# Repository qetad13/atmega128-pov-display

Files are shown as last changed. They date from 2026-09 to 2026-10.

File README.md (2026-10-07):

# ATmega128 POV Display — 회전 LED 잔상 디스플레이

> 마이크로프로세서 수업 Term Project · **2025.08 – 2025.11** · 4인 팀 (팀장) — 회로·PCB·펌웨어·기구 설계 전담

## 프로젝트 개요

| | |
|---|---|
| **소개** | 세로 한 줄로 배치한 **RGB LED 16개**를 모터로 회전시키고, 회전에 맞춰 열(column) 데이터를 빠르게 바꿔 **잔상(POV)으로 글자와 그림을 공중에 그리는** 디스플레이. LED 구동 PCB 설계 → 펌웨어 → 3D 프린팅 기구까지 직접 구현했습니다. |
| **기획 의도** | LED 16개는 그 자체로는 세로 **선** 하나에 불과합니다. 하지만 이 선을 회전시키면서 정확한 타이밍에 빛을 바꾸면, 사람 눈의 잔상 효과로 선이 지나간 자리가 **면**이 되어 글자와 그림이 떠오릅니다. **부품 수를 늘리는 대신 시간으로 해상도를 만든다**는 발상에 끌려 주제로 골랐습니다.<br><br>같은 발상을 배선에도 적용했습니다. RGB LED 16개를 직접 제어하려면 핀이 48개 필요하지만, 시프트 레지스터 6개를 한 줄로 엮어 데이터를 직렬로 흘려보내면 **핀 3개면 충분합니다.** 수업에서 배운 ATmega128의 **타이머 · PWM · 외부 인터럽트 · GPIO 제어**를 이 하나의 작품에 통합했고, 이전 프로젝트에서 겪은 만능기판 배선의 한계를 넘기 위해 **KiCad로 PCB를 직접 설계**했습니다. |
| **하이라이트** | 🔆 **선 → 면** : LED 한 줄(16개)을 회전시켜 잔상으로 2차원 화면 구현<br>📌 **48 → 3** : 74HC595 체인으로 LED 48채널을 MCU 핀 3개로 제어<br>🎨 **단색 8행 → RGB 16행** : 해상도 2배, 6색 · 6단계 밝기 표현 |
| **내 역할** | **팀장** — 회로 설계, PCB 아트웍·제작, 펌웨어(LED 보드 · 모터 보드), 기구 3D 모델링, 설계 문서 |
| **기여도** | **90%** — 하드웨어·펌웨어·기구 설계를 사실상 단독으로 구현 (자세한 내용은 [내 담당 범위](#내-담당-범위)) |

## 주요 사양

| 항목 | 내용 |
|---|---|
| MCU | ATmega128 × 2 (LED 보드 / 모터 보드) |
| LED | RGB LED 16개 (16행 × R·G·B = 48채널) |
| LED 드라이버 | 74HC595 ×6 데이지 체인 (48비트) — **MCU 핀 3개로 48채널 구동** |
| 모터 | DC 모터 + L298N 모터 드라이버, Timer0 Fast PWM 속도 제어 |
| 입력 | 택트 스위치 → 외부 인터럽트 (LED 4개 + 모터 3개) |
| 기능 | 6색 전환 · 6단계 밝기 · 패턴 2종(글자 `ISA` / 하트) · 모터 속도 ±, 일시정지 |
| 개발 환경 | CodeVisionAVR (C), KiCad 9, Fusion 360 |
| 상태 | **완료** — 2025.08 – 2025.11 마이크로프로세서 수업 텀프로젝트 (이후 추가 개발 없음) |

<p align="center">
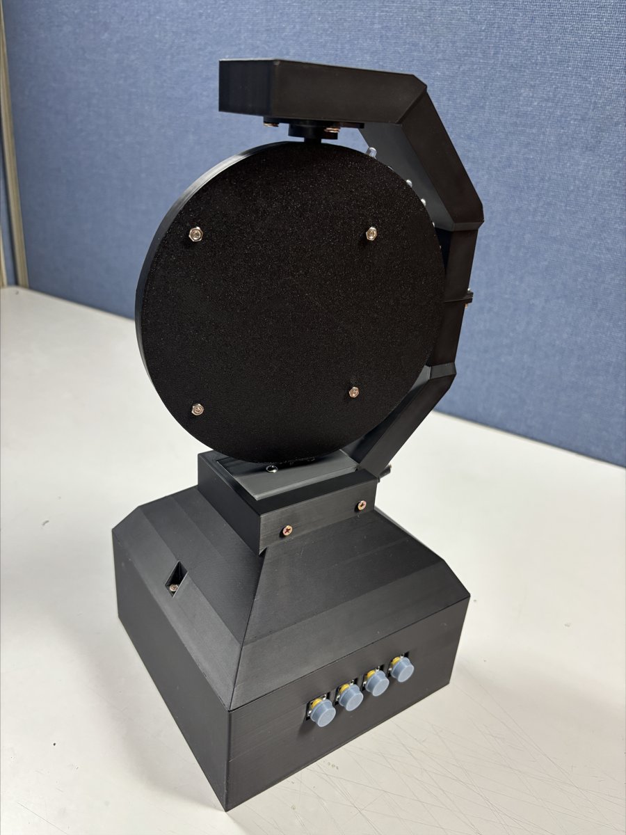
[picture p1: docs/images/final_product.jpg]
  
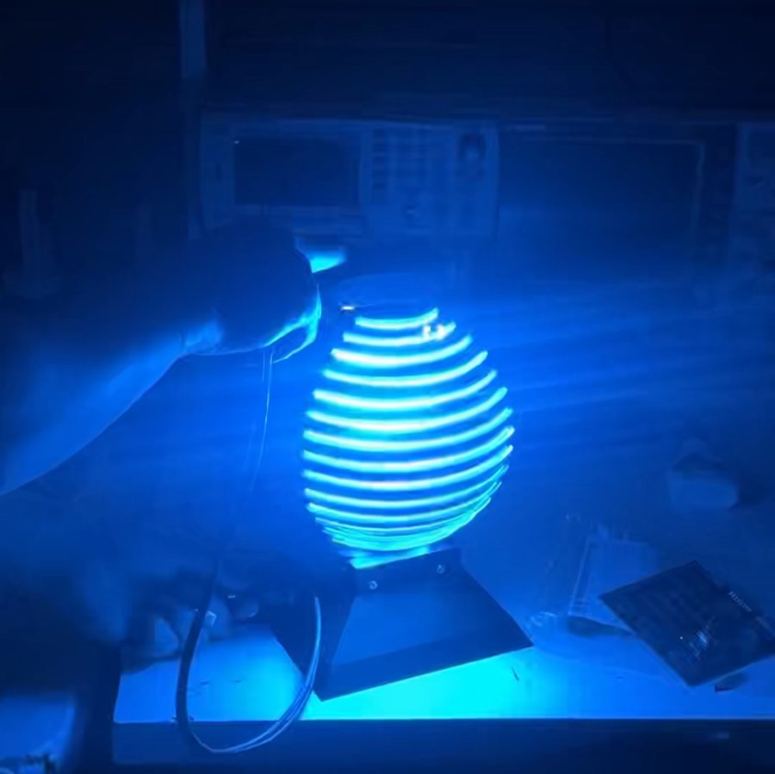
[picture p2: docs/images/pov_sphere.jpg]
  
  <br><sub>왼쪽 완성품 · 오른쪽 회전 중 잔상 — LED 한 줄이 회전하며 구(球) 형태의 면을 만듦</sub>
</p>

---

## 시스템 구조



- **고정부**: 12V 어댑터 → L298N이 모터를 구동하고, L298N의 5V 출력으로 모터 보드와 회전부에 전원 공급
- **회전부**: 전원은 **슬립링**을 통해 회전판 위 LED 보드로 전달되며, MCU가 74HC595 체인으로 RGB LED 16개를 구동

### 동작 원리

1. **LED 한 열 출력** — 16비트 열 패턴을 색상에 따라 R/G/B 채널에 배치하고, B → G → R 순서로 48비트를 시프트한 뒤 RCLK로 한 번에 래치
   - 비트가 `0`이면 LED 켜짐(Active-Low), `0xFFFF`는 전체 소등
2. **밝기 (소프트웨어 PWM)** — 한 열을 `uptime` ms 동안 켜고 `7 - uptime` ms 동안 꺼서, 7 ms 주기 안에서 듀티비를 1/7 ~ 6/7로 조절
3. **패턴** — 회전하는 동안 열 데이터를 순서대로 바꿔 출력하면 잔상으로 2차원 이미지가 보임
   - `ISA` 글자: 24열 (글자당 8열), 하트: 12열
4. **모터 속도** — Timer0 Fast PWM의 `OCR0` 값(0~254)을 인터럽트로 ±10씩 바꿔 L298N ENA에 입력

### 제어 흐름



### 핀 배치

**LED 보드 (ATmega128 #1)**

| 핀 | 방향 | 용도 |
|---|---|---|
| PA0 | 출력 | 74HC595 SER / DS (직렬 데이터) |
| PA1 | 출력 | 74HC595 SRCLK / SHCP (시프트 클럭) |
| PA2 | 출력 | 74HC595 RCLK / STCP (래치 클럭) |
| PD0 (INT0) | 입력, 풀업 | 색상 전환 (빨 → 초 → 파 → 노 → 마젠타 → 청록) |
| PD1 (INT1) | 입력, 풀업 | 밝기 변경 (1 ↔ 6 단계 왕복) |
| PD2 (INT2) | 입력, 풀업 | 패턴 1: `ISA` 글자 |
| PD3 (INT3) | 입력, 풀업 | 패턴 2: 하트 |

**모터 보드 (ATmega128 #2)**

| 핀 | 방향 | 용도 |
|---|---|---|
| PB4 (OC0) | 출력 | PWM → L298N ENA |
| PA0 / PA1 | 출력 | L298N IN1 / IN2 (회전 방향 고정) |
| PD0 (INT0) | 입력, 풀업 | 속도 +10 (최대 254) |
| PD1 (INT1) | 입력, 풀업 | 속도 −10 (최소 1) |
| PD2 (INT2) | 입력, 풀업 | 일시정지 / 재시작 (직전 속도 복원, 첫 시작 160) |

인터럽트는 모두 하강 에지 트리거(`EICRA`)입니다.

---

## 폴더 구조

```
atmega128-pov-display/
├─ firmware/                  CodeVisionAVR C 소스
│  ├─ led_board/main.c        74HC595 48비트 시프트 출력, 색상·밝기·패턴 제어
│  └─ motor_board/main.c      Timer0 Fast PWM 모터 속도 제어
├─ hardware/
│  └─ pcb/                    KiCad 9 프로젝트 (LED 보드)
│     ├─ MPMP.kicad_pro / .kicad_sch / .kicad_pcb
│     └─ gerber/              제작용 Gerber + 드릴 파일
├─ mechanical/                3D 프린팅 부품 (STL)
│  ├─ rotor_plate.stl         회전판 (PCB 장착)
│  ├─ rotor_cover_v2.stl      회전판 덮개
│  ├─ support_upper.stl       지지대 (위)
│  ├─ support_lower.stl       지지대 (아래)
│  ├─ base.stl                받침대
│  └─ base_support.stl        받침대 하부 받침
└─ docs/
   ├─ images/                 블록 다이어그램, 플로우차트, PCB · 3D · 결과 사진
   └─ videos/                 동작 영상
```

---

## 하드웨어

### LED 보드 PCB

- **크기**: 90.3 × 87.2 mm, 2층, 두께 1.6 mm (KiCad 9)
- **구성**
  - ATmega128-16A (TQFP-64) + 크리스털, 22 pF 부하 커패시터, 리셋 스위치
  - 74HC595 × 6 (R·G·B 각 2개, 채널당 16비트) + 칩별 0.1 µF 바이패스 커패시터
  - 8연 저항 네트워크(R_Network08) × 2
  - LED 연결 패드 48개 (R/G/B × 16), 10핀 ISP 헤더 (PE0 / PE1 / PB1 / RESET)
  - 고정용 마운팅 홀 4개
- 48채널 LED 배선을 회전체에 싣기 위해 MCU와 시프트 레지스터를 한 장의 보드로 통합

| PCB 레이아웃 | PCB 3D 뷰 | 회전판 조립 (LED 48채널 배선) |
|:---:|:---:|:---:|
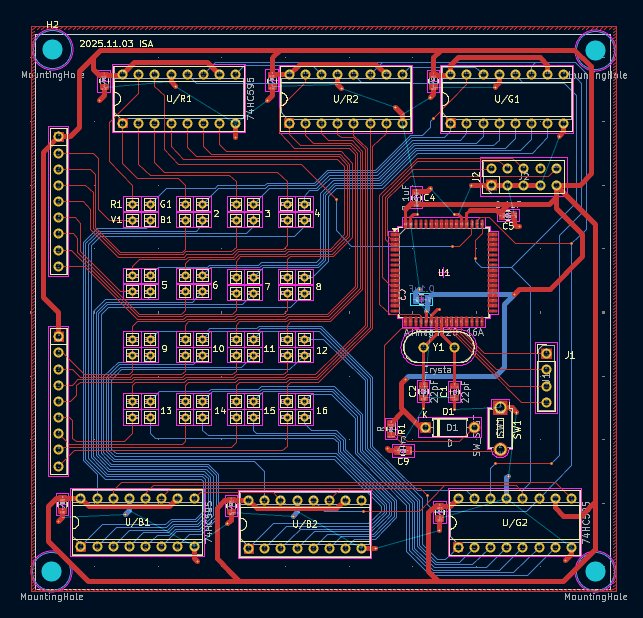
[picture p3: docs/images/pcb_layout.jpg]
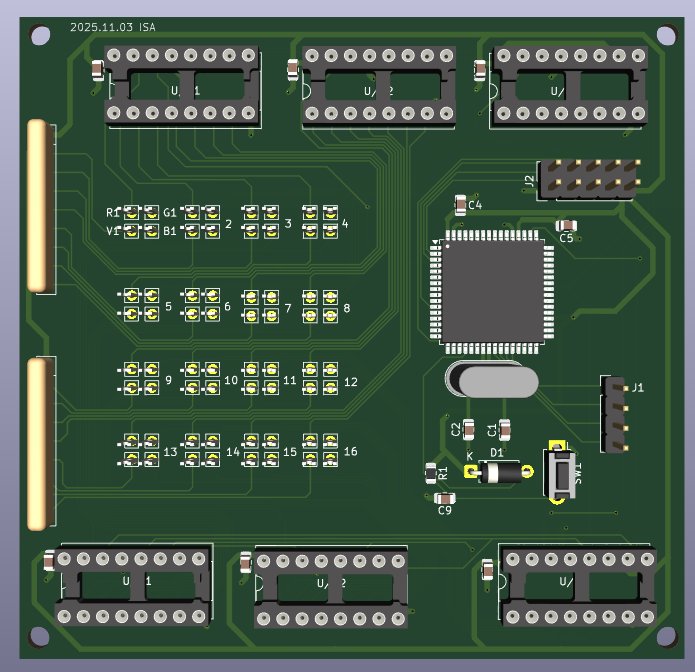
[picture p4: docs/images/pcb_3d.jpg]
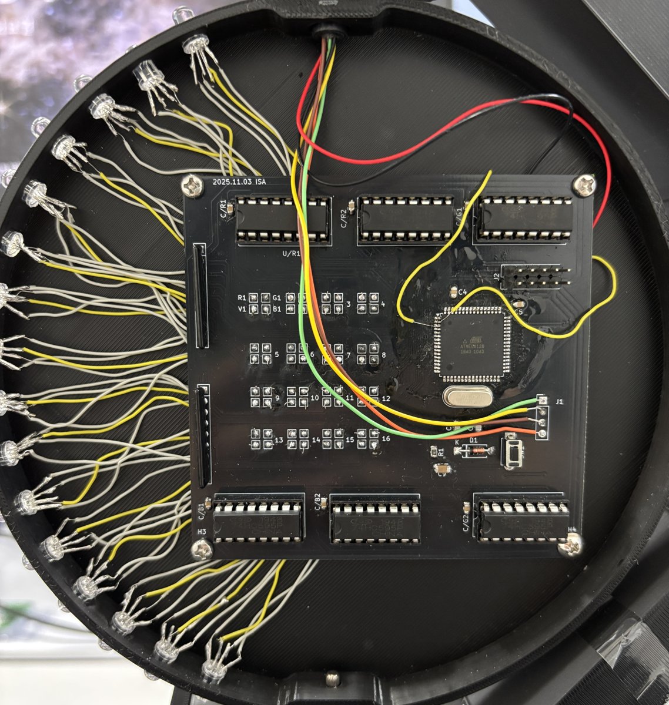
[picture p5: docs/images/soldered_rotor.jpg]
|  |  |  |

브레드보드 테스트를 거친 뒤 PCB로 제작했습니다 ([브레드보드 사진](docs/images/breadboard.jpg)).

### 기구부

- 회전판에 PCB와 LED를 고정하고, 모터 축에 연결해 회전
- 지지대(위/아래)와 받침대로 모터와 회전부를 고정
- 회전부 전원은 슬립링을 통해 공급 (회전하는 LED 보드에 VCC · GND 전달)

| 회전판 · 덮개 | 지지대 · 받침대 | 최종 조립 모델 |
|:---:|:---:|:---:|
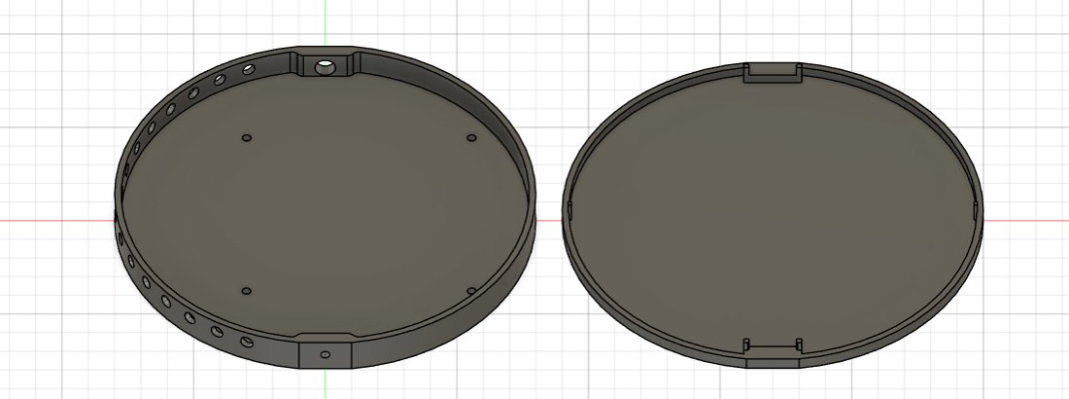
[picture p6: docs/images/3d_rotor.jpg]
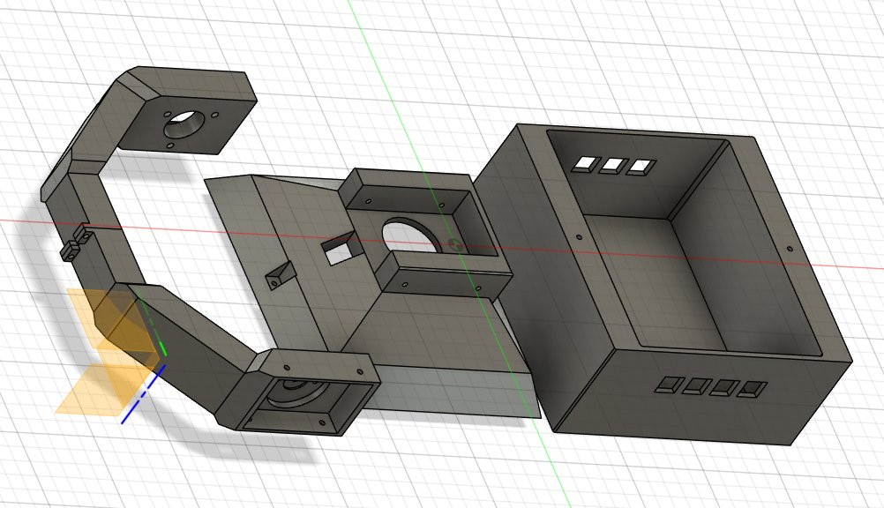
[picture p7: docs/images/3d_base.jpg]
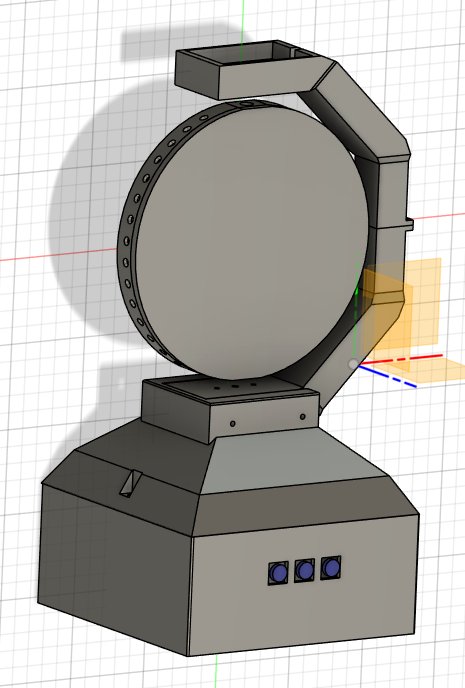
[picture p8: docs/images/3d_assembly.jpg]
|  |  |  |

---

## 결과

### RGB 출력

| Red | Green | Blue |
|:---:|:---:|:---:|
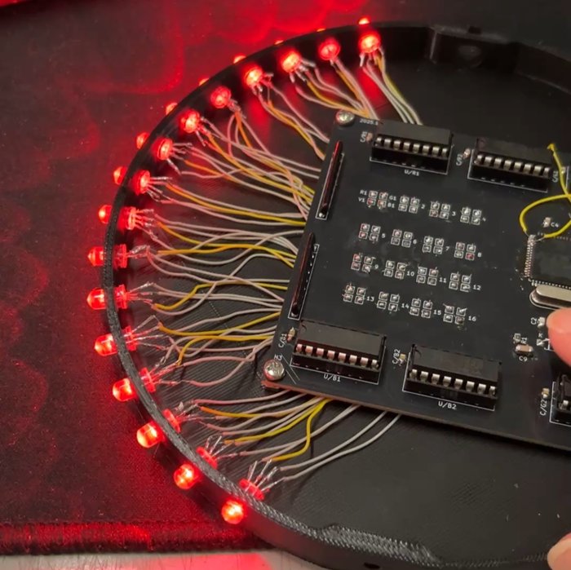
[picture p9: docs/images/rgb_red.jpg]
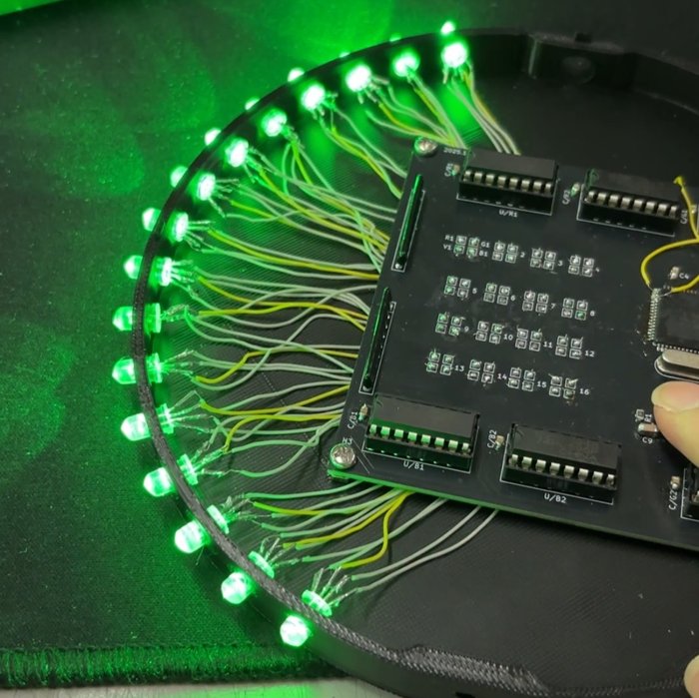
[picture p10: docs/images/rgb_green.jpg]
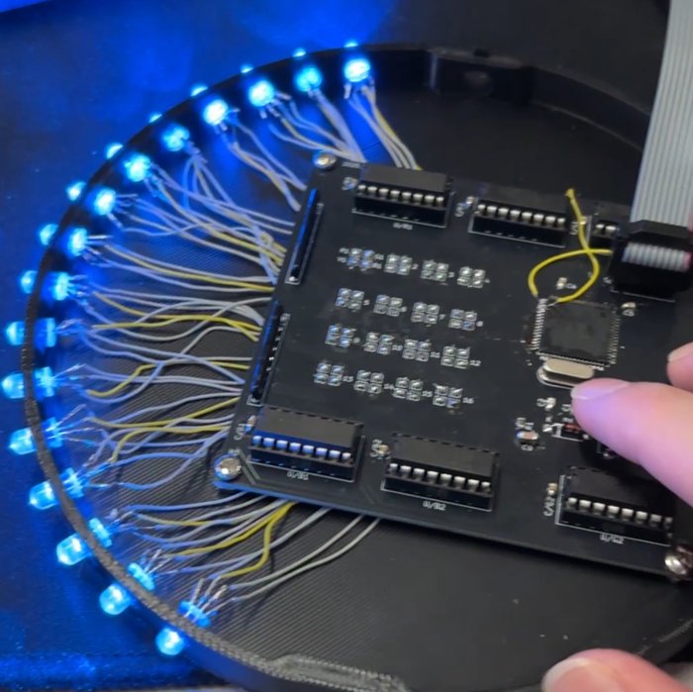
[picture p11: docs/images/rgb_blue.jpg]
|  |  |  |

### 잔상으로 글자 출력 (`ISA`)

| I | S | A |
|:---:|:---:|:---:|
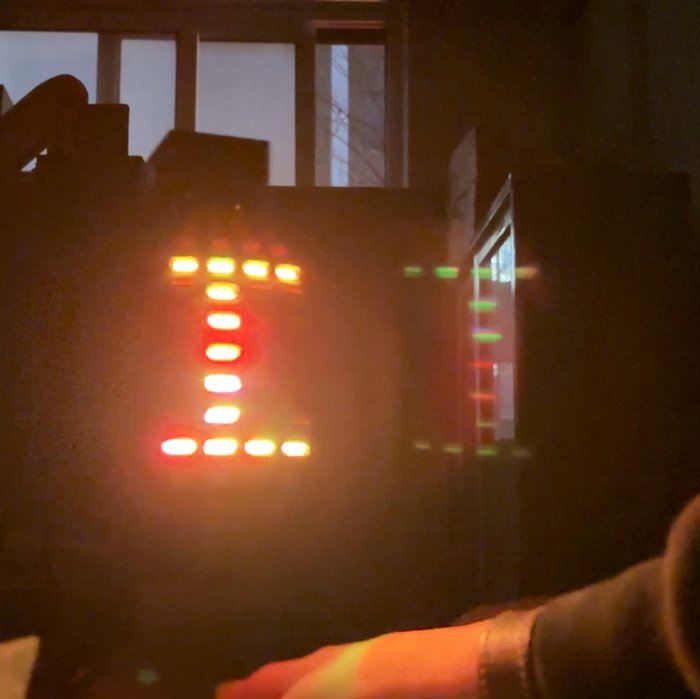
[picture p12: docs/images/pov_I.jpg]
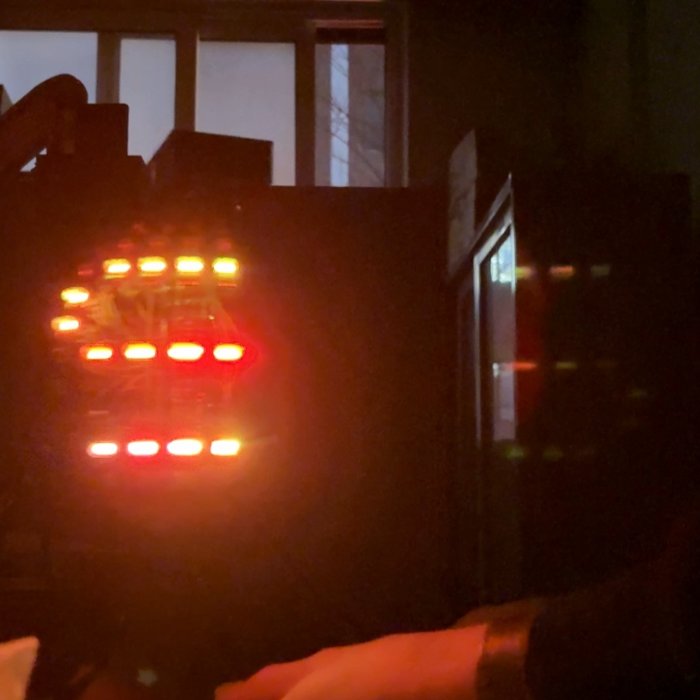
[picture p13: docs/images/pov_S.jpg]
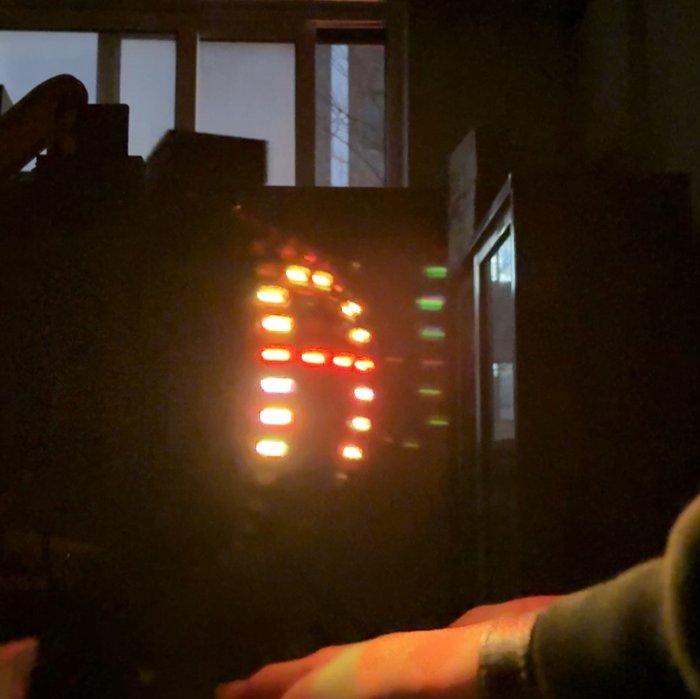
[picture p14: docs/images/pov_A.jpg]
|  |  |  |

### 동작 영상

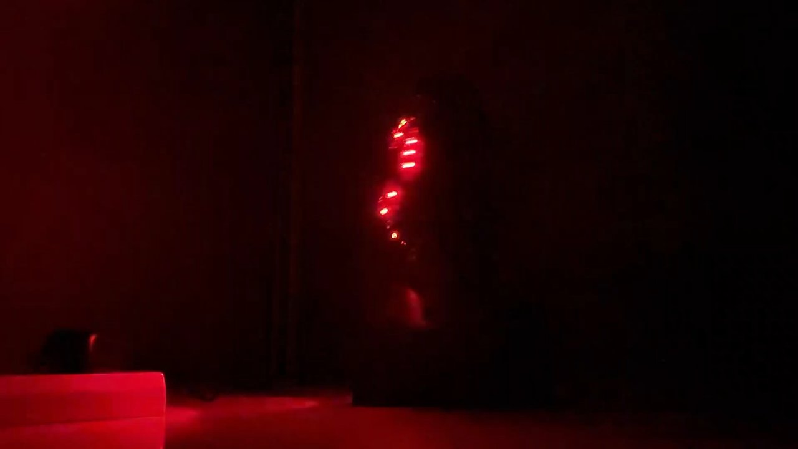
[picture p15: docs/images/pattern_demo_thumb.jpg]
패턴 출력 동작 영상


▶ [`docs/videos/pattern_demo.mp4`](docs/videos/pattern_demo.mp4) — 회전하며 패턴을 출력하는 모습

---

## 내 담당 범위

4인 팀 프로젝트에서 제가 담당한 부분입니다.

| 파트 | 내용 |
|---|---|
| 회로 / PCB | LED 보드 회로도 설계, PCB 아트웍, Gerber 출력 및 제작 |
| 펌웨어 | LED 보드(시프트 레지스터 구동, 색상·밝기·패턴 제어), 모터 보드(PWM 속도 제어) |
| 기구 | 회전판, 덮개, 지지대, 받침대 3D 모델링 및 출력 |
| 설계 문서 | 블록 다이어그램, 제어 플로우차트, 핀 배치 |

---

## 트러블슈팅

### 1. RGB · 16행으로 확장하자 GPIO가 부족해진 문제
- **배경**: 처음에는 단색 LED 8개(8행)로 설계했으나, 두 가지를 바꾸기로 함
  - 한 가지 색으로 고정된 표현이 아쉬워 **RGB LED**로 변경 → 여러 색상 표현
  - 글자와 그림을 더 선명하게 표시하기 위해 **8행 → 16행**으로 해상도 확장
- **문제**: RGB LED 16개를 GPIO로 직접 제어하면 16행 × R·G·B 3색 = **48핀**이 필요 (단색 8행일 때는 8핀) → ATmega128 포트 대부분을 LED에만 써야 해서 버튼 인터럽트 등 다른 기능에 쓸 핀이 부족
- **해결**: 74HC595 시프트 레지스터 6개를 직렬로 연결해 48비트를 직렬로 전송하고 래치로 한 번에 출력
  - MCU 핀 **3개**(SER · SRCLK · RCLK = PA0~2)만으로 LED 48채널 전체 제어
  - 남은 포트는 버튼 인터럽트(INT0~3)와 ISP 프로그래밍에 사용
- **결과**: 단색 8행 → RGB 16행(6색 표현)으로 확장하면서 LED 제어용 GPIO는 48개 → 3개로 줄임

### 2. MCU를 하나로 합치지 못한 문제 (미해결)
- **상황**: 기능만 보면 ATmega128 하나로 LED 표시와 모터 PWM 제어를 모두 처리할 수 있음
- **원인**: LED 보드는 회전판 위에서 돌고 L298N·모터는 고정부에 있음. MCU를 하나로 합치면 전원뿐 아니라 모터 제어선(PWM, 방향 IN1·IN2)이나 버튼 신호도 슬립링을 거쳐야 하는데, 사용한 **슬립링의 선 수가 부족**해 신호선을 추가로 넘길 수 없었음
- **대응**: 모터 제어부(고정)와 디스플레이부(회전)로 나누어 ATmega128을 각각 사용
- **개선 방향**: 선 수가 더 많은 슬립링을 쓰면 MCU 하나로 통합해 부품 수와 배선을 줄일 수 있음
  - 프로젝트가 종료되어 이 구조로 마무리했고, 이후 수정은 진행하지 않음

---

## 실행 방법

### 1. 펌웨어 빌드 및 업로드
1. CodeVisionAVR에서 새 프로젝트 생성 → Chip: **ATmega128**, 클럭은 보드 크리스털에 맞게 설정
2. LED 보드는 `firmware/led_board/main.c`, 모터 보드는 `firmware/motor_board/main.c`를 프로젝트에 추가
3. Build 후 ISP 프로그래머로 각 보드에 업로드
   - `mega128.h`, `delay.h`는 CodeVisionAVR에 포함된 헤더입니다

### 2. 조작
| 보드 | 스위치 | 동작 |
|---|---|---|
| 모터 | INT2 | 모터 시작 / 일시정지 (전원 투입 시 정지 상태) |
| 모터 | INT0 / INT1 | 속도 증가 / 감소 |
| LED | INT2 / INT3 | `ISA` 글자 / 하트 패턴 |
| LED | INT0 | 색상 전환 (6색) |
| LED | INT1 | 밝기 변경 |

LED 보드는 전원 투입 시 R → G → B를 0.3초씩 켜서 LED 상태를 확인한 뒤 대기합니다.

### 3. PCB 제작
- `hardware/pcb/gerber/` 폴더 전체를 압축해 PCB 제작 업체에 업로드
- 설계 수정은 KiCad 9에서 `hardware/pcb/MPMP.kicad_pro` 열기

### 4. 기구 출력
- `mechanical/*.stl`을 슬라이서에서 열어 3D 프린터로 출력

---

## 기술 스택
`C (CodeVisionAVR)` `AVR ATmega128` · `KiCad 9` · `Fusion 360`

## 라이선스 / 출처
- [MIT License](LICENSE)
- 이 저장소의 코드, 회로 및 기구 설계는 모두 직접 작성했으며 외부 코드는 포함하지 않았습니다.
- `mega128.h`, `delay.h`: CodeVisionAVR 컴파일러 기본 헤더 (저장소에 미포함)
- PCB 회로도/풋프린트: KiCad 기본 라이브러리 심볼·풋프린트 사용 (CC-BY-SA 4.0, 설계물에 대한 예외 조항 적용)

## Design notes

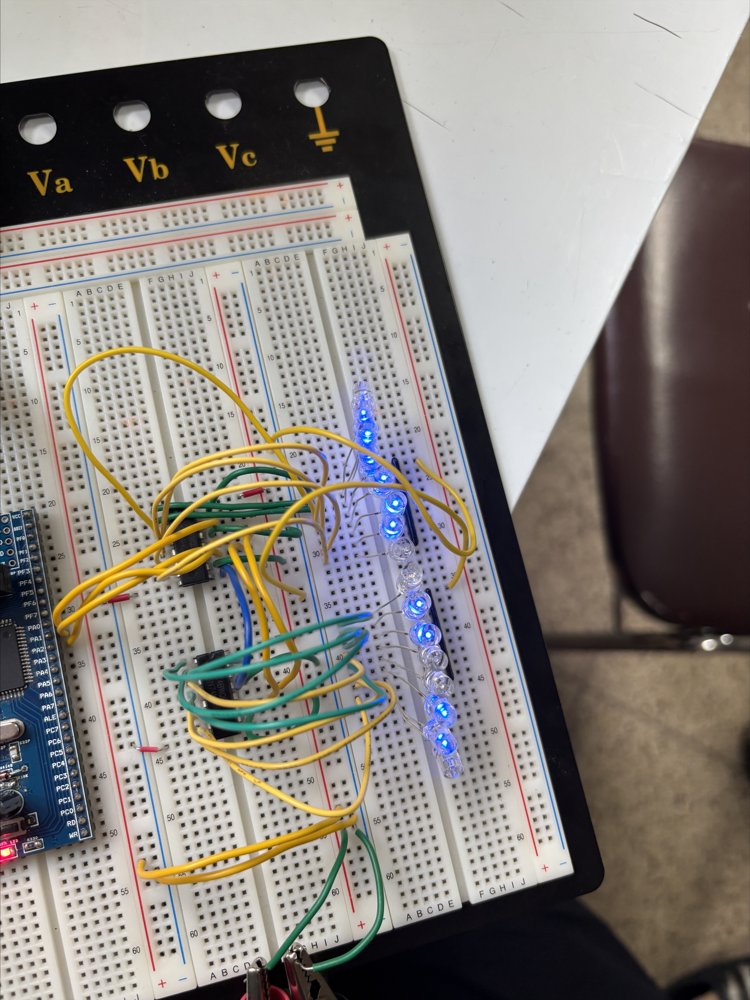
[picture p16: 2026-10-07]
docs/images/breadboard.jpg

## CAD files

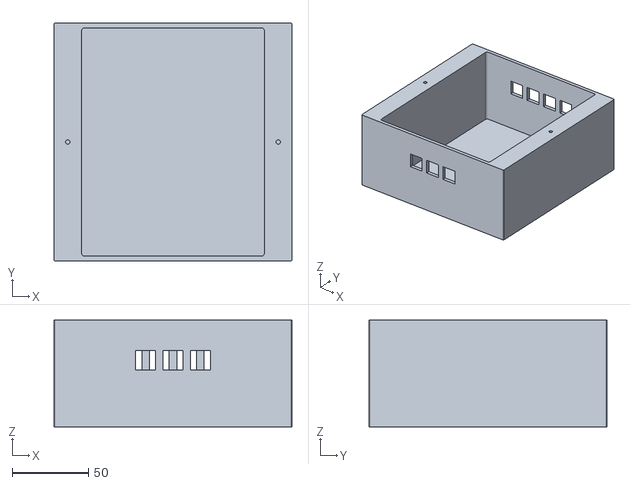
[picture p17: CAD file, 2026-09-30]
mechanical/base_support.stl
156.2 x 156.2 x 70.0

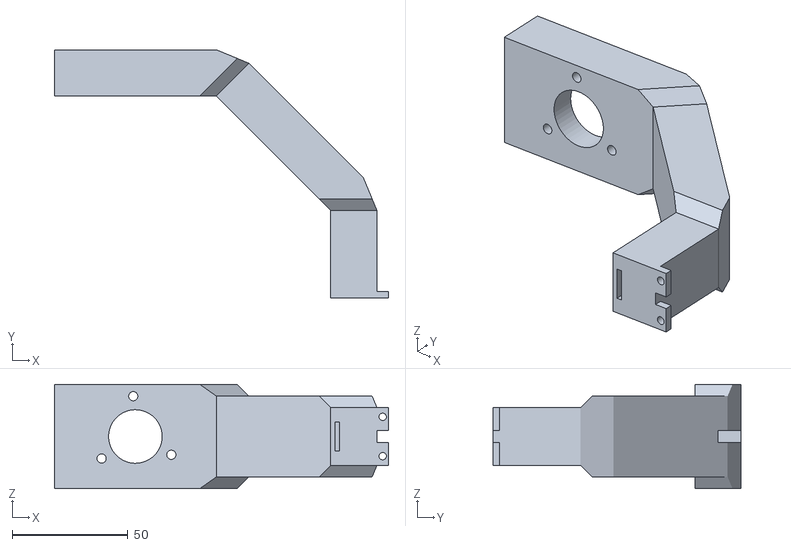
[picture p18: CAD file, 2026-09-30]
mechanical/support_upper.stl
144.5 x 107.5 x 45.0

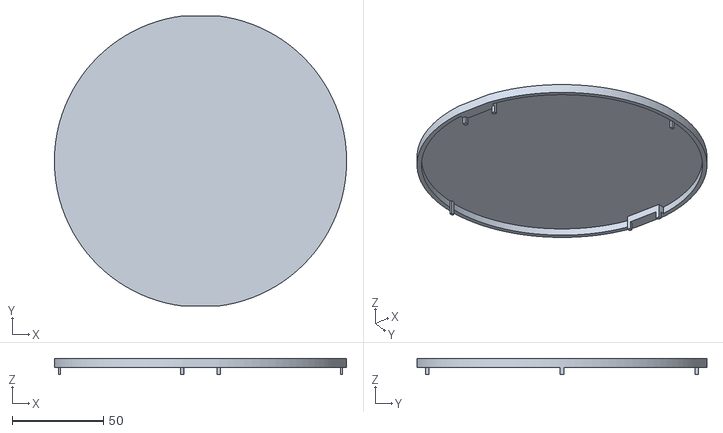
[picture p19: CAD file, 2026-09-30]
mechanical/rotor_cover_v2.stl
159.9 x 158.7 x 9.00

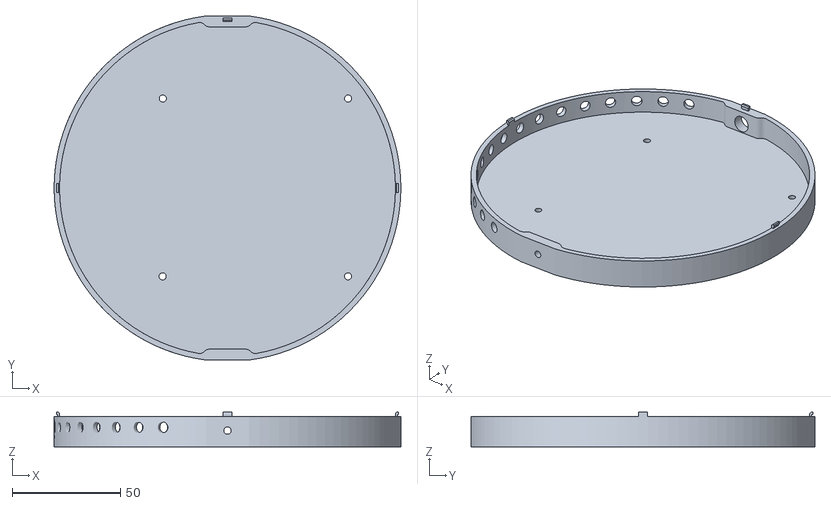
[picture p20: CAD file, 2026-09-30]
mechanical/rotor_plate.stl
159.9 x 158.7 x 16.0

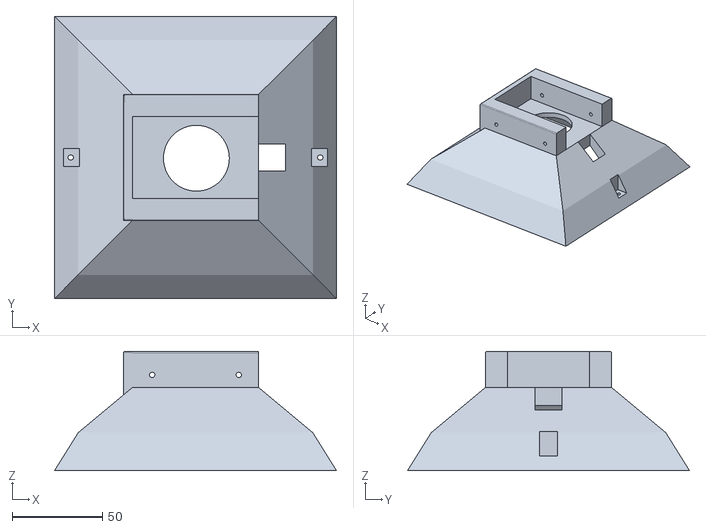
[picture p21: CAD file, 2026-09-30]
mechanical/base.stl
156.2 x 156.2 x 66.0

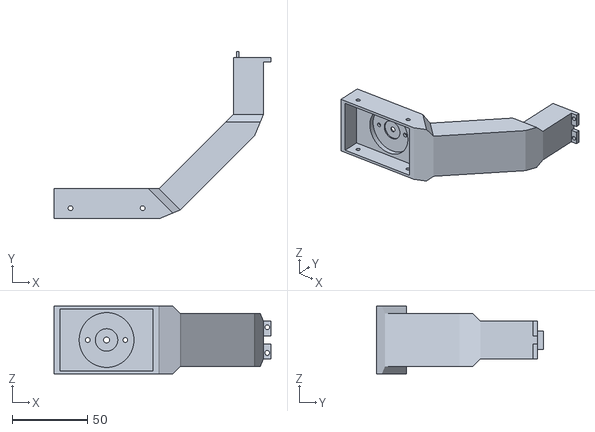
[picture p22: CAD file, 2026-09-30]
mechanical/support_lower.stl
144.5 x 111.5 x 45.0

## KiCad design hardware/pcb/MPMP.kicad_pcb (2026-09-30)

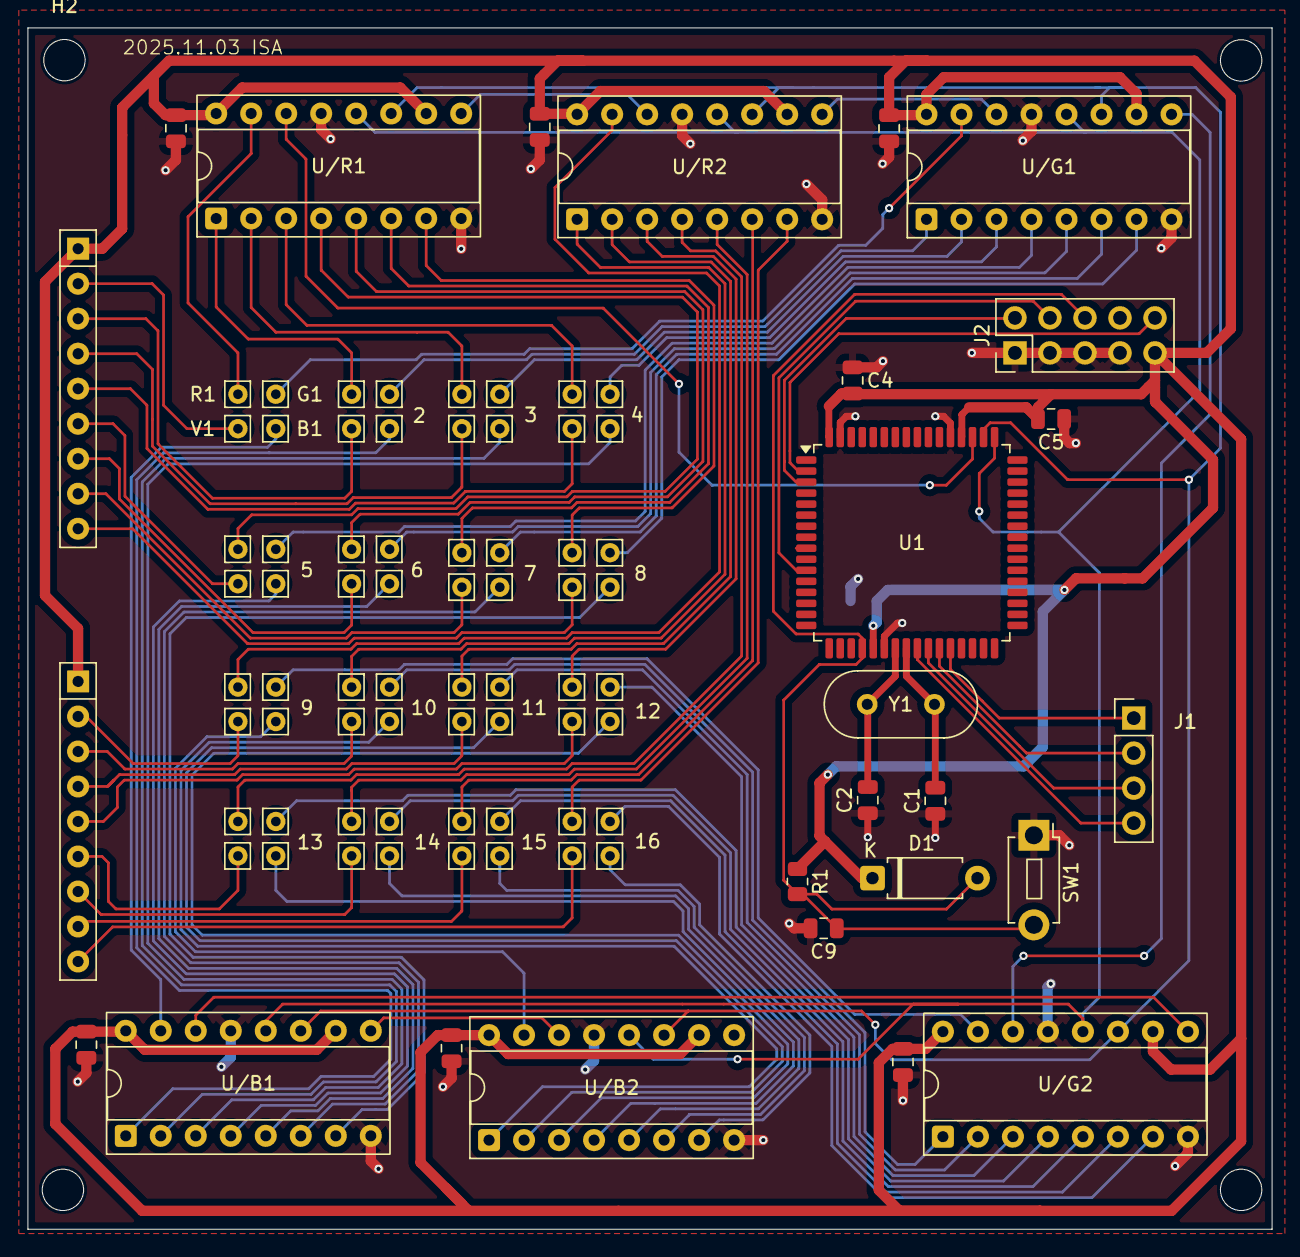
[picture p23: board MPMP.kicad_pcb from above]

Board: 2 copper layers, 90.3 x 87.2 mm, 95 parts (1 on the bottom side), 84 nets.

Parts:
2, 3, 4, 5, 6, 7, 8, 9, 10, 11, 12, 13, 14, 15, 16: Conn_01x01_Pin; Pin_D0.7mm_L6.5mm_W1.8mm_FlatFork
B1: Conn_01x01_Pin; Pin_D0.7mm_L6.5mm_W1.8mm_FlatFork
C1, C2: 22pF; C_0805_2012Metric
C3, C4, C5: 0.1uF; C_0805_2012Metric
C9: C; C_0805_2012Metric
C/B1, C/B2: C_Small; C_0805_2012Metric
C/G1, C/G2: C_Small; C_0805_2012Metric
C/R1, C/R2: C_Small; C_0805_2012Metric
D1: D; D_A-405_P7.62mm_Horizontal
G1: Conn_01x01_Pin; Pin_D0.7mm_L6.5mm_W1.8mm_FlatFork
H1, H2, H3, H4: MountingHole; MountingHole_3mm
J1: Conn_01x04_Pin; PinHeader_1x04_P2.54mm_Vertical
J2: Conn_01x10_Pin; PinHeader_2x05_P2.54mm_Vertical
J/B2, J/B3, J/B4, J/B5, J/B6, J/B7, J/B8, J/B9, J/B11, J/B12, J/B13, J/B15, J/B16: Conn_01x01_Pin; Pin_D0.7mm_L6.5mm_W1.8mm_FlatFork
J/G10, J/G11, J/G12, J/G14, J/G15, J/G16: Conn_01x01_Pin; Pin_D0.7mm_L6.5mm_W1.8mm_FlatFork
J/R2, J/R3, J/R4, J/R5, J/R6, J/R7, J/R8, J/R9, J/R10, J/R12, J/R13, J/R14, J/R15, J/R16: Conn_01x01_Pin; Pin_D0.7mm_L6.5mm_W1.8mm_FlatFork
J/V2, J/V3, J/V4, J/V5, J/V6, J/V7, J/V8, J/V9, J/V10, J/V11, J/V13, J/V14: Conn_01x01_Pin; Pin_D0.7mm_L6.5mm_W1.8mm_FlatFork
R1: Conn_01x01_Pin; Pin_D0.7mm_L6.5mm_W1.8mm_FlatFork
R1#2: R; R_0805_2012Metric
RN1, RN2: R_Network08; R_Array_SIP9
SW1: SW_SPST; SW_PUSH_1P1T_6x3.5mm_H4.3_APEM_MJTP1243
U1: ATmega128-16A; TQFP-64_14x14mm_P0.8mm
U/B1, U/B2: 74HC595; DIP-16_W7.62mm_Socket
U/G1, U/G2: 74HC595; DIP-16_W7.62mm_Socket
U/R1, U/R2: 74HC595; DIP-16_W7.62mm_Socket
V1: Conn_01x01_Pin; Pin_D0.7mm_L6.5mm_W1.8mm_FlatFork
Y1: Crystal; Crystal_HC49-U_Vertical

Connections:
/PB1: J2.4, U1.11 (PB1)
/PE0: J2.10, U1.2 (PE0)
/PE1: J2.2, U1.3 (PE1)
/RCLK/STCP: U1.49 (PA2), U/B1.12 (RCLK), U/B2.12 (RCLK), U/G1.12 (RCLK), U/G2.12 (RCLK), U/R1.12 (RCLK), U/R2.12 (RCLK)
/RESET: C9.1, D1.2 (A), J2.6, R1#2.2, SW1.2 (B), U1.20 (~RESET)
/SER/DS: U1.51 (PA0), U/R1.14 (SER)
/SRCLK/SHCP: U1.50 (PA1), U/B1.11 (SRCLK), U/B2.11 (SRCLK), U/G1.11 (SRCLK), U/G2.11 (SRCLK), U/R1.11 (SRCLK), U/R2.11 (SRCLK)
GND: C1.1, C2.1, C3.1, C4.1, C5.1, C9.2, C/B1.2, C/B2.2, C/G1.2, C/G2.2, C/R1.2, C/R2.2, J2.1, J2.3, J2.5, J2.7, SW1.1 (A), U1.22 (GND), U1.53 (GND), U1.63 (GND), U/B1.8 (GND), U/B1.13 (~OE), U/B2.8 (GND), U/B2.13 (~OE), U/G1.8 (GND), U/G1.13 (~OE), U/G2.8 (GND), U/G2.13 (~OE), U/R1.8 (GND), U/R1.13 (~OE), U/R2.8 (GND), U/R2.13 (~OE)
unnamed: J1.1, U1.28 (PD3)
unnamed: J1.2, U1.27 (PD2)
unnamed: J1.3, U1.26 (PD1)
unnamed: J1.4, U1.25 (PD0)
unnamed: B1.1, U/B1.15 (QA)
unnamed: J/B2.1, U/B1.1 (QB)
unnamed: J/B3.1, U/B1.2 (QC)
unnamed: J/B4.1, U/B1.3 (QD)
unnamed: J/B5.1, U/B1.4 (QE)
unnamed: J/B6.1, U/B1.5 (QF)
unnamed: J/B7.1, U/B1.6 (QG)
unnamed: J/B8.1, U/B1.7 (QH)
unnamed: J/B9.1, U/B2.15 (QA)
unnamed: 10.1, U/B2.1 (QB)
unnamed: J/B11.1, U/B2.2 (QC)
unnamed: J/B12.1, U/B2.3 (QD)
unnamed: J/B13.1, U/B2.4 (QE)
unnamed: 14.1, U/B2.5 (QF)
unnamed: J/B15.1, U/B2.6 (QG)
unnamed: J/B16.1, U/B2.7 (QH)
unnamed: G1.1, U/G1.15 (QA)
unnamed: 2.1, U/G1.1 (QB)
unnamed: 3.1, U/G1.2 (QC)
unnamed: 4.1, U/G1.3 (QD)
unnamed: 5.1, U/G1.4 (QE)
unnamed: 6.1, U/G1.5 (QF)
unnamed: 7.1, U/G1.6 (QG)
unnamed: 8.1, U/G1.7 (QH)
unnamed: 9.1, U/G2.15 (QA)
unnamed: J/G10.1, U/G2.1 (QB)
unnamed: J/G11.1, U/G2.2 (QC)
unnamed: J/G12.1, U/G2.3 (QD)
unnamed: 13.1, U/G2.4 (QE)
unnamed: J/G14.1, U/G2.5 (QF)
unnamed: J/G15.1, U/G2.6 (QG)
unnamed: J/G16.1, U/G2.7 (QH)
unnamed: R1.1, U/R1.15 (QA)
unnamed: J/R2.1, U/R1.1 (QB)
unnamed: J/R3.1, U/R1.2 (QC)
unnamed: J/R4.1, U/R1.3 (QD)
unnamed: J/R5.1, U/R1.4 (QE)
unnamed: J/R6.1, U/R1.5 (QF)
unnamed: J/R7.1, U/R1.6 (QG)
unnamed: J/R8.1, U/R1.7 (QH)
unnamed: J/R9.1, U/R2.15 (QA)
unnamed: J/R10.1, U/R2.1 (QB)
unnamed: 11.1, U/R2.2 (QC)
unnamed: J/R12.1, U/R2.3 (QD)
unnamed: J/R13.1, U/R2.4 (QE)
unnamed: J/R14.1, U/R2.5 (QF)
unnamed: J/R15.1, U/R2.6 (QG)
unnamed: J/R16.1, U/R2.7 (QH)
unnamed: RN1.2 (R1), V1.1
unnamed: J/V2.1, RN1.3 (R2)
unnamed: J/V3.1, RN1.4 (R3)
unnamed: J/V4.1, RN1.5 (R4)
unnamed: J/V5.1, RN1.6 (R5)
unnamed: J/V6.1, RN1.7 (R6)
unnamed: J/V7.1, RN1.8 (R7)
unnamed: J/V8.1, RN1.9 (R8)
unnamed: J/V9.1, RN2.2 (R1)
unnamed: J/V10.1, RN2.3 (R2)
unnamed: J/V11.1, RN2.4 (R3)
unnamed: 12.1, RN2.5 (R4)
unnamed: J/V13.1, RN2.6 (R5)
unnamed: J/V14.1, RN2.7 (R6)
unnamed: 15.1, RN2.8 (R7)
unnamed: 16.1, RN2.9 (R8)
unnamed: C1.2, U1.24 (XTAL1), Y1.2
unnamed: C2.2, U1.23 (XTAL2), Y1.1
unnamed: U/B1.9 (QH'), U/B2.14 (SER)
unnamed: U/B1.14 (SER), U/G2.9 (QH')
unnamed: U/G1.9 (QH'), U/G2.14 (SER)
unnamed: U/G1.14 (SER), U/R2.9 (QH')
unnamed: U/R1.9 (QH'), U/R2.14 (SER)
VCC: C3.2, C4.2, C5.2, C/B1.1, C/B2.1, C/G1.1, C/G2.1, C/R1.1, C/R2.1, D1.1 (K), J2.9, R1#2.1, RN1.1 (common), RN2.1 (common), U1.21 (VCC), U1.52 (VCC), U1.64 (AVCC), U/B1.10 (~SRCLR), U/B1.16 (VCC), U/B2.10 (~SRCLR), U/B2.16 (VCC), U/G1.10 (~SRCLR), U/G1.16 (VCC), U/G2.10 (~SRCLR), U/G2.16 (VCC), U/R1.10 (~SRCLR), U/R1.16 (VCC), U/R2.10 (~SRCLR), U/R2.16 (VCC)

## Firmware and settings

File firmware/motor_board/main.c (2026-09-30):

#include <mega128.h>
#include <delay.h>

// 초기값은 멈춰있는 상태에서 시작이라는 것을 가정
volatile unsigned char motor_speed = 0;     // 현재 모터 속도
volatile unsigned char saved_motor_speed = 160; // 멈추기 직전 속도 저장
volatile unsigned char motor_stop_flag = 1;  // 모터 정지 플래그 (0=동작, 1=정지)

// Timer 0을 8비트 고속 PWM 모드로 초기화
void pwm_init_timer0(void) {
    DDRB.4 = 1;
    TCCR0 = (1 << WGM01) | (1 << WGM00) | (1 << COM01) | (1 << CS01) | (1 << CS00);
    OCR0 = 0; 
}

// 모터 속도 설정
void motor_set_speed(unsigned char speed) {
    OCR0 = speed; 
}

// INT0 - 속도 증가
interrupt [EXT_INT0] void int0_isr(void) {
    if (motor_stop_flag == 0) { 
        if (motor_speed <= 245) {
            motor_speed += 10;
        }
        else {
            motor_speed = 254;
        }
    }
}

// INT1 - 속도 감소
interrupt [EXT_INT1] void int1_isr(void) {
    if (motor_stop_flag == 0) {
        if (motor_speed >= 20) {
            motor_speed -= 10;
        }
        else {
            motor_speed = 1; // 최소 속도
        }
    }   
}

// INT2 - 일시정지 / 재시작
interrupt [EXT_INT2] void int2_isr(void) {
    if (motor_stop_flag == 0) {
        saved_motor_speed = motor_speed;
        motor_speed = 0;
        motor_stop_flag = 1;
    }
    else {
        motor_speed = saved_motor_speed;
        motor_stop_flag = 0;
    }   
}

void main(void) {
    DDRA.0 = 1;
    DDRA.1 = 1;
    
    // 2. PWM 초기화 (Timer 0)
    pwm_init_timer0();
    
    PORTD.0 = 1;
    PORTD.1 = 1;
    PORTD.2 = 1;
    
    EICRA = 0x2a;
    EIMSK = 0x07;
    
    PORTA.0 = 1;    // 모터 방향 설정
    PORTA.1 = 0;
    
    #asm("sei")

    while (1) {
        motor_set_speed(motor_speed);   // 주기적으로 반복하며 인터럽트에서 변경된 속도값을 PWM에 적용
        
        delay_ms(10); 
    }
}

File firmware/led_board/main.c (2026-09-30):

#include <mega128.h>
#include <delay.h>

#define SER   0  // PORTA.0     DS (Serial Data)
#define SRCLK 1  // PORTA.1     SHCP (Shift Clock)
#define RCLK  2  // PORTA.2     STCP (Latch Clock)

// 변수 선언
volatile unsigned int led_state = 0; // LED 상태를 저장(0부터 5까지 6가지 색상)
int isa_flag = 0;
int heart_flag = 0;
int delay_time = 1;
volatile unsigned int led_shape = 0x0000;
volatile unsigned int uptime = 4;
volatile unsigned int uptime_flag = 0;  // 0이 밝아지기 1이 어두워지기 
volatile unsigned int led_R = 0x0000;  // shiftOutRGB 함수에 전달할 R값
volatile unsigned int led_G = 0xFFFF;  // G값
volatile unsigned int led_B = 0xFFFF;  // B값

// 함수 정의
void update_led_colors();
void bright();
void shift_16_bits(unsigned int data);
void shiftOutRGB(unsigned int r_data, unsigned int g_data, unsigned int b_data);

void update_led_colors() {
    switch(led_state) {
        case 0: // 빨간색
            led_R = led_shape;
            led_G = 0xFFFF;
            led_B = 0xFFFF;
            break;
        case 1: // 초록색
            led_R = 0xFFFF;
            led_G = led_shape;
            led_B = 0xFFFF;
            break;
        case 2: // 파란색
            led_R = 0xFFFF;
            led_G = 0xFFFF;
            led_B = led_shape;
            break;
        case 3: // 빨,초 : 노란색
            led_R = led_shape;
            led_G = led_shape;
            led_B = 0xFFFF;
            break;
        case 4: // 빨, 파 : 마젠타
            led_R = led_shape;
            led_G = 0xFFFF;
            led_B = led_shape;
            break;
        case 5: // 초, 파 : 청록색
            led_R = 0xFFFF;
            led_G = led_shape;
            led_B = led_shape;
            break;
    }
}
void bright() {
    update_led_colors();
    
    shiftOutRGB(led_R, led_G, led_B);
        
    delay_ms(uptime);
    shiftOutRGB(0xFFFF, 0xFFFF, 0xFFFF);
    delay_ms(7-uptime);
}
// 인터럽트
interrupt [EXT_INT0] void ext_int0_isr(void) {
    led_state++;    // 버튼 한 번 누를 때 마다 하나 씩 증가
    if(led_state > 5) { // 청록색 다음에는 다시 빨간색으로 
        led_state = 0;
    }
    
    update_led_colors();
}

interrupt [EXT_INT1] void ext_int1_isr(void) {
    if (uptime_flag == 0) {    
        if (uptime > 0) {
            uptime--;
        }
        
        if (uptime == 0) { 
            uptime_flag = 1;
            uptime++;
        }                           
    }
    if (uptime_flag == 1) { 
        if (uptime < 7) {
            uptime++;
        }
        
        if (uptime == 7) {
            uptime_flag = 0;
            uptime--;
        }
    }
}

interrupt [EXT_INT2] void ext_int2_isr(void) {
    isa_flag = 1;
    heart_flag = 0;
}

interrupt [EXT_INT3] void ext_int3_isr(void) {
    heart_flag = 1;
    isa_flag = 0;
}


// 16비트 데이터를 시프트 해주는 함수
void shift_16_bits(unsigned int data) {
    unsigned char i;

    for(i=0;i<16;i++) {
        // 최상위 비트(MSB)부터 전송
        if(data & 0x8000) PORTA |= (1<<SER);
        else              PORTA &= ~(1<<SER);

        // 시프트 클럭 ↑↓ (데이터 1비트 이동)
        PORTA |= (1<<SRCLK);
        PORTA &= ~(1<<SRCLK);

        data <<= 1; // 다음 비트 준비
    }
}

// 48비트 (16비트 x 3) 데이터 출력 함수
void shiftOutRGB(unsigned int r_data, unsigned int g_data, unsigned int b_data) {
    // Blue 데이터부터 전송, B -> G -> R
    shift_16_bits(b_data); 
    shift_16_bits(g_data);
    shift_16_bits(r_data);

    // 48비트 전송이 모두 완료되면 래치 클럭(RCLK) -> 출력
    PORTA |= (1<<RCLK);
    PORTA &= ~(1<<RCLK);
}

void main(void) {
     // 입출력 포트 설정
     DDRA = 0x07;  // 00000111, PA0,1,2 출력
     PORTA = 0x00;
     DDRD = 0x00;   // PD0,1,2,3 핀 입력
     PORTD = 0X0F; // PD0,1,2,3 핀 풀업저항 활성화

     // 외부 인터럽트 설정
     EIMSK = 0x0F;  // INT 0,1,2,3 인터럽트 활성화
     EICRA = 0xAA;  // INT 0,1,2,3 하강에지
 
     #asm("sei") // 전역 인터럽트 활성화

    update_led_colors(); // led_state(0)에 맞는 R,G,B 값 로드

    // R,G,B 한 번씩 출력
    shiftOutRGB(0x0000, 0xFFFF, 0xFFFF);    
    delay_ms(300);
    shiftOutRGB(0xFFFF, 0xFFFF, 0xFFFF);
    delay_ms(300);    
    shiftOutRGB(0xFFFF, 0x0000, 0xFFFF);    
    delay_ms(300);
    shiftOutRGB(0xFFFF, 0xFFFF, 0xFFFF);
    delay_ms(300);
    shiftOutRGB(0xFFFF, 0xFFFF, 0x0000);
    delay_ms(300);
    
    
    while(1) {
        bright();
        
        if (isa_flag == 1) {
            led_shape = 0xffff; bright(); delay_ms(delay_time);
            led_shape = 0xfbef; bright(); delay_ms(delay_time);
            led_shape = 0xf80f; bright(); delay_ms(delay_time);
            led_shape = 0xfbef; bright(); delay_ms(delay_time);
            led_shape = 0xfbef; bright(); delay_ms(delay_time);
            led_shape = 0xffff; bright(); delay_ms(delay_time);
            led_shape = 0xffff; bright(); delay_ms(delay_time);
            led_shape = 0xffff; bright(); delay_ms(delay_time);

            led_shape = 0xff9f; bright(); delay_ms(delay_time);
            led_shape = 0xfb6f; bright(); delay_ms(delay_time);
            led_shape = 0xfb6f; bright(); delay_ms(delay_time);
            led_shape = 0xfb6f; bright(); delay_ms(delay_time);
            led_shape = 0xfb6f; bright(); delay_ms(delay_time);
            led_shape = 0xfcff; bright(); delay_ms(delay_time);
            led_shape = 0xffff; bright(); delay_ms(delay_time);
            led_shape = 0xffff; bright(); delay_ms(delay_time);

            led_shape = 0xffff; bright(); delay_ms(delay_time);
            led_shape = 0xffff; bright(); delay_ms(delay_time);
            led_shape = 0xf81f; bright(); delay_ms(delay_time);
            led_shape = 0xff6f; bright(); delay_ms(delay_time);
            led_shape = 0xff6f; bright(); delay_ms(delay_time);
            led_shape = 0xf81f; bright(); delay_ms(delay_time);
            led_shape = 0xffff; bright(); delay_ms(delay_time);
            led_shape = 0xffff; bright(); delay_ms(delay_time);
        }
        
        if (heart_flag == 1) {
            led_shape = 0xffff; bright(); delay_ms(delay_time);
            led_shape = 0xfe7f; bright(); delay_ms(delay_time);
            led_shape = 0xf81f; bright(); delay_ms(delay_time);
            led_shape = 0xe007; bright(); delay_ms(delay_time);
            led_shape = 0x8001; bright(); delay_ms(delay_time);
            led_shape = 0x0007; bright(); delay_ms(delay_time);
            led_shape = 0x0007; bright(); delay_ms(delay_time);
            led_shape = 0x8001; bright(); delay_ms(delay_time);
            led_shape = 0xe007; bright(); delay_ms(delay_time);
            led_shape = 0xf81f; bright(); delay_ms(delay_time);
            led_shape = 0xfe7f; bright(); delay_ms(delay_time);
            led_shape = 0xffff; bright(); delay_ms(delay_time);
        } 
    }
}

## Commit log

2026-09-30 Initial commit: ATmega128 POV LED display
    - firmware: LED board (74HC595 x6, color/brightness/pattern) and motor board (Timer0 PWM)
    - hardware: KiCad 9 LED board project and Gerber files
    - mechanical: 3D-printed rotor, cover, supports and base (STL)
    - docs: block diagram, flowchart, README
    [MPMP-B_Cu.gbr, MPMP-B_Mask.gbr, MPMP-B_Paste.gbr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]
2026-09-30 Redraw block diagram and flowchart as SVG
    - Block diagram: two ATmega128 boards, slip ring power path, pin-level signals
    - Flowchart: separate LED/motor board flows with ISRs matching the firmware
    - Remove old PNGs and the redundant mermaid diagram from README
2026-10-07 Highlight line-to-plane and 3-pin/48-channel design in overview
2026-10-07 Add photos and demo video from presentation
    PCB, rotor assembly, 3D models, RGB output, POV letter results,
    and pattern demo video.
